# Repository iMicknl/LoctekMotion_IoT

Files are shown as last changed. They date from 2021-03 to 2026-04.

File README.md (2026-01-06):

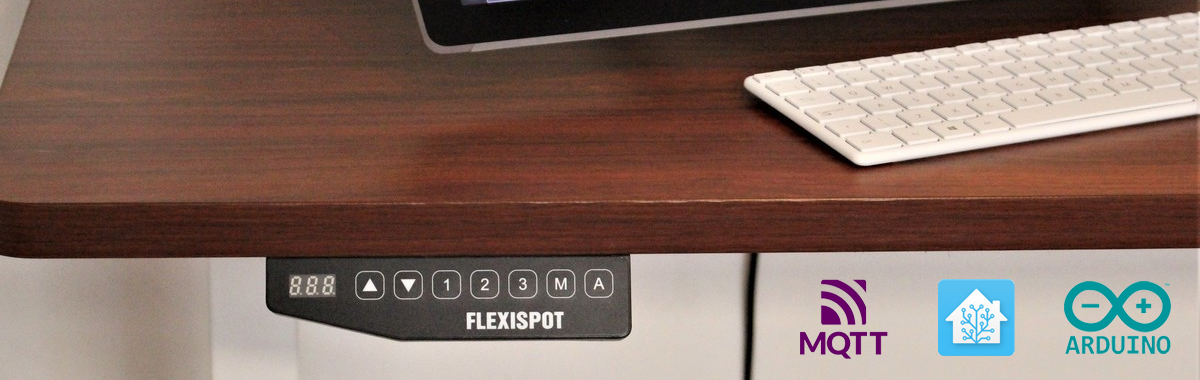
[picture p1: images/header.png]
Flexispot Desk with automation logos

(*image source: [Windows Central](https://www.windowscentral.com/flexispot-e5-standing-desk-review)*)

> [!WARNING]
> Be careful. Tinkering with electronics can be risky. Use this guide at your own risk.

## Turn your LoctekMotion/FlexiSpot desk into a smart desk

When I assembled my FlexiSpot standing desk, I noticed the control panel had an RJ45 cable and a second RJ45 port. This sparked my interest: can I connect my desk to the internet?

Most Flexispot models utilize components from LoctekMotion, a manufacturer specializing in lifting columns for height-adjustable desks. Although LoctekMotion previously advertised a [Bluetooth receiver](https://www.loctekmotion.com/shop/accessories/bt-desk-app/) for their control boxes, I haven't been able to obtain one.

This repository will guide you on connecting your desk to Home Assistant and other systems using the serial communication ports (RJ45). Imagine controlling your desk with your voice or receiving notifications when you've been sitting too long. Or, just do it because it's cool 🤓.

## Features

- Control your desk (up, down, stop) using a cover entity
- Manage 4 presets with button entities
- Monitor desk height with a sensor entity
- Adjust desk height in cm using a number entity *(experimental)*

#### Known issues

- Number entity may overshoot. The desk moves until the height sensor matches the requested height, which may cause overshooting due to reporting delays. Use the desk controller presets for accurate positioning.

## Packages

| Name | Description |
| --- | --- |
| [ESPHome](packages/office-desk-esp32.yaml) | Control your desk via an ESP32 module connected to Home Assistant. Can be adapted to ESP8266 or other ESP32 variant. |
| [ESPHome Pass-through](packages/office-desk-esp32-passthrough.yaml)  | Control desks which have only one RJ45 port using passthrough configuration via an ESP32 module connected to Home Assistant. |

For v1 packages (Arduino, Raspberry Pi, older ESPHome packages, and different pin-outs), visit the [`archive`](./archive/) directory. For alternative solutions, see [similar projects](#similar-projects).

## Getting started

Please follow the [ESPHome documentation](https://esphome.io/guides/getting_started_command_line.html) for the basics of ESPHome. You can use the provided [`office-desk-esp32.yaml`](https://github.com/iMicknl/LoctekMotion_IoT/blob/main/packages/office-desk-esp32.yaml) as a boilerplate for your own implementation. This implementation has been created for the ESP32 nodemcu, but can easily be adopted for other platforms and boards.

### Pin-out

| RJ45 pin | Name | ESP32 |
| --- | --- | --- |
| 8 | +5V (VDD) | VIN |
| 7 | GND | GND |
| 6 | TX | TX2 (GPIO17) |
| 5 | RX | RX2 (GPIO16) |
| 4 | PIN 20 | D23 (GPIO23) |
| 3 | (unknown) | |
| 2 | SWIM | |
| 1 | RES | |

This pin-out should be compatible with all control panels featuring an RJ45 port for serial communication. If it doesn't work for your setup, consider trying an alternative pin-out from the [archive](./archive/esphome/README.md).

Use the provided pin-out to connect your ESP32 to the desk controller's RJ45 port using an ethernet cable. If you're not experienced with electronics and soldering, consider using an RJ45 Adapter Board from sites like Aliexpress, connected with Dupont cables to your ESP32.

example setup

#### Pass-Through Configuations

If your desk controller lacks an extra RJ45 port, you'll need a pass-through solution. This requires connecting the RJ45 of the keypad to the pins below.

| KeyPad RJ45 pin | Name | Connection
| --- | --- | ---
| 8 | +5V (VDD) |  VIN  (Split)
| 7 | GND |  GND  (Split)
| 6 | TX |  RX0  (GPIO3)
| 5 | RX |  RX2  (Split)
| 4 | PIN 20 |  (Not Required)
| 3 | (unknown) |  (Not Required)
| 2 | SWIM |  (Pass-Through)
| 1 | RES |  (Pass-Through)

The pins marked 'split' are to be connected to the ESP32 pin, the desk controller and to the keypad. The pins marked pass-through are to be connected directly between the controller and the keypad.

Note: the current implementation does not utilize PIN20 however, this could be utilized to sense if the screen is on if desired.

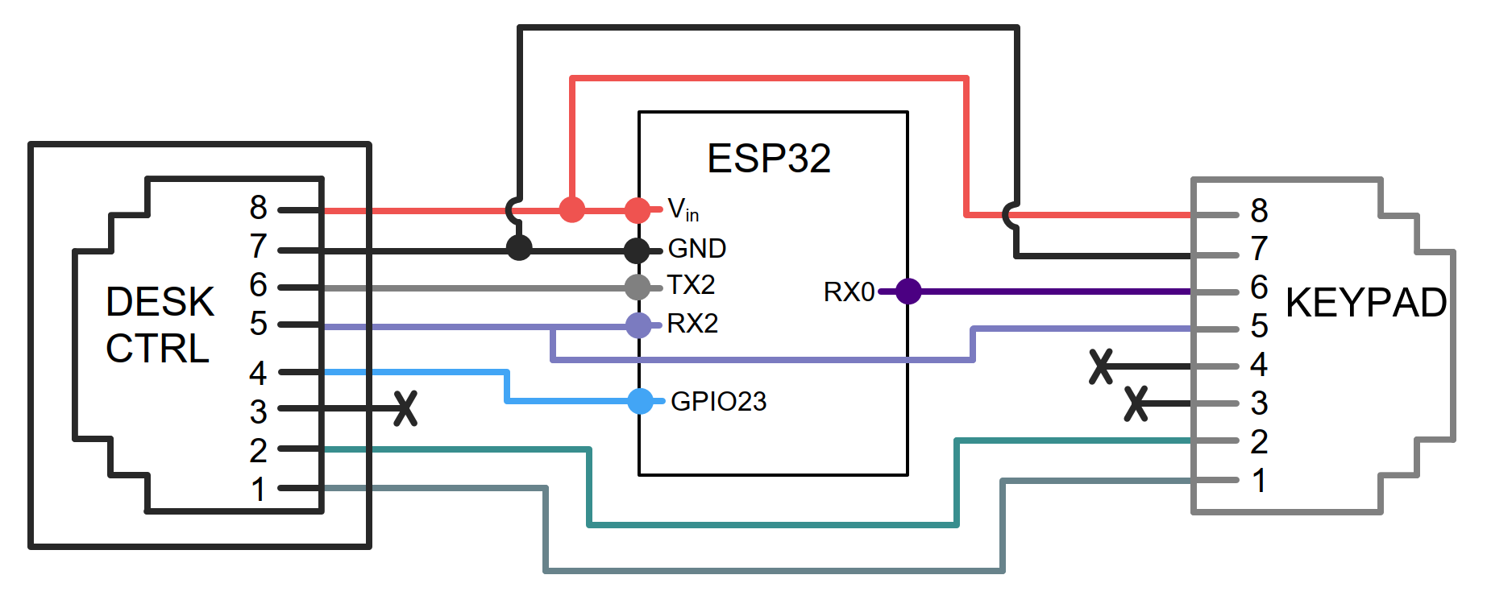
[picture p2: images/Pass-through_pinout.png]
Pass-Through Pinout


### Optional: Custom Enclosure for a Clean Setup

To keep your setup clean and well-protected, a custom enclosure for the ESP32 DevKit with Ethernet breakout is available. It ensures secure housing, optimal cable management, and a stable wired connection.

Features ✅:
- Secure housing – Protects the ESP32 and Ethernet breakout
- Optimized cable management – Keeps wiring neat and organized
- Ventilation slots – Prevents overheating
- Easy mounting – Designed for a hassle-free installation
- Compact design – Fits seamlessly into any setup

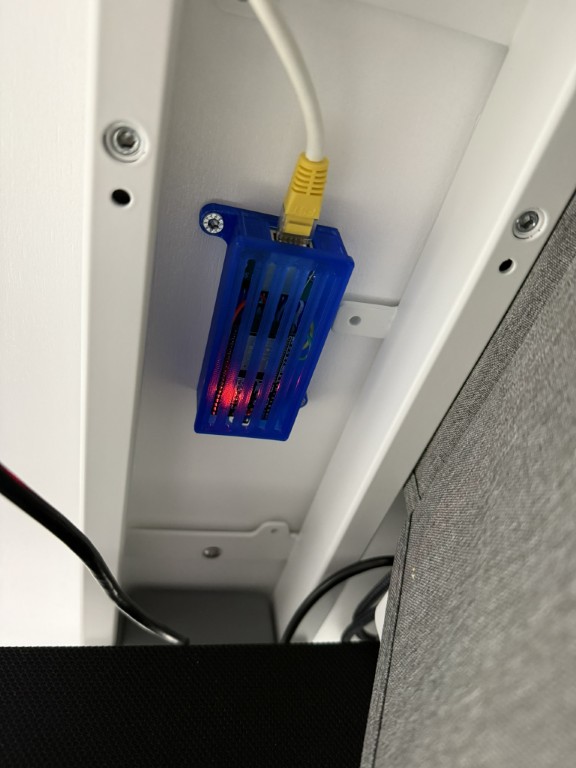
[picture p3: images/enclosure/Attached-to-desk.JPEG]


🔗 Download the enclosure model at [makerworld.com](https://makerworld.com/de/models/1220796-flexispot-smartdesk-enclosure-esp32-devkit-lan#profileId-1237633).

### Troubleshooting

**My height sensor is not providing the correct value**
- Uncomment the debug line for UART in the ESPHome configuration to see the raw data coming from the desk controller. This will help you collect information to troubleshoot the issue. See [debugging UART](https://esphome.io/components/uart.html#debugging).
- If your cover entity has up/down buttons grayed out due to height sensor issues, you can change the internal parameter for the up/down switch from `true` to `false`in the YAML configuration.

## Research

If you are interested in the internals of the LoctecMotion desk system, have a look at the research below which is composed of my own findings combined with findings of [similar projects](#similar-projects).

<details>

<summary>Full research</summary>

### Control Panels

At the time of writing, LoctekMotion sells [11 different control panels](https://www.loctekmotion.com/product/control-panel/). The features can differ per model, but it looks like the serial interface is pretty similar for the more advanced models.

The tables below will show a mapping of the RJ45 pinout to the pinout used by the control panel. Please note that all RJ45 pins are described in the following way:

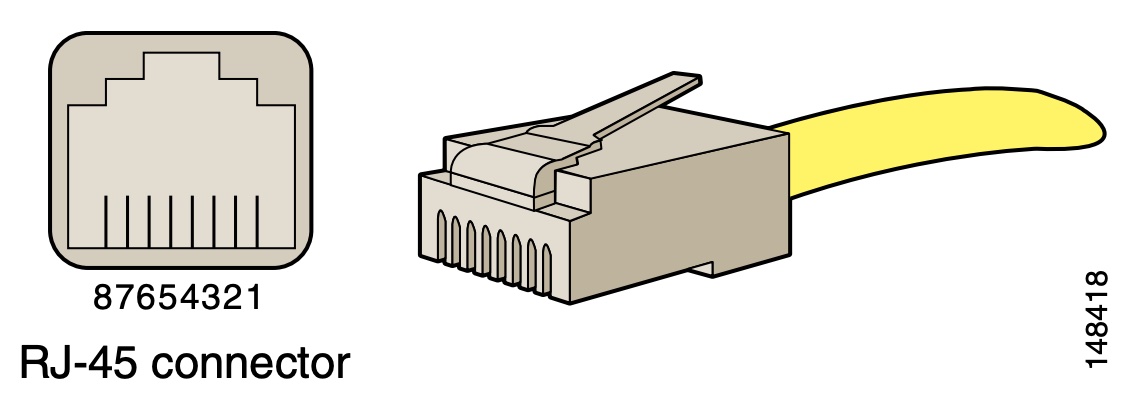
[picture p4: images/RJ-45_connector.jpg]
RJ-45 connector layout


The most common [color convention](https://www.showmecables.com/blog/post/rj45-pinout)
for wiring RJ45 for network cables is:

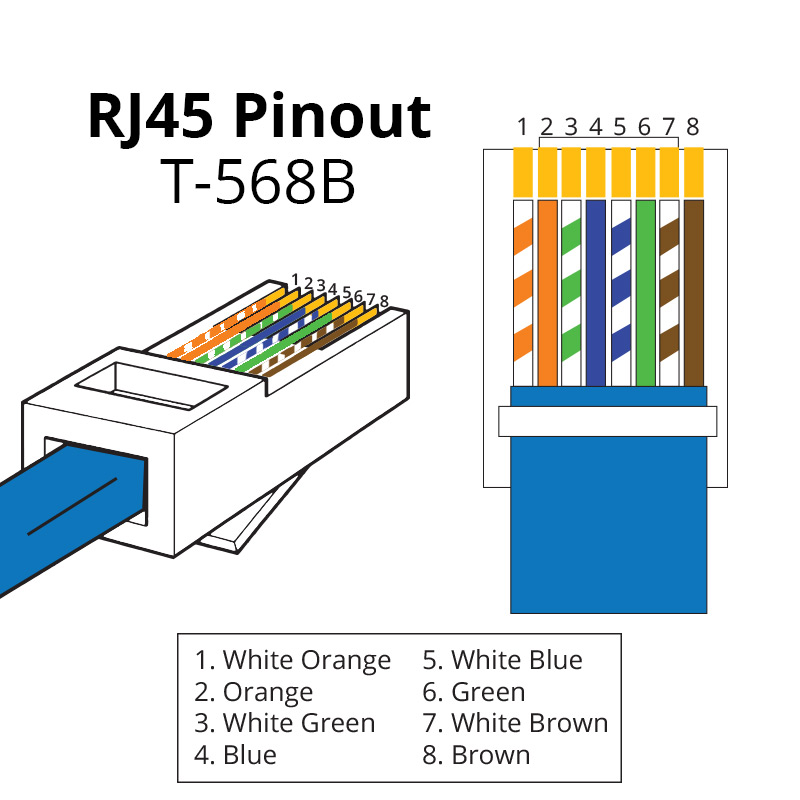
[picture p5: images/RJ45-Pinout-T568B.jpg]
RJ45 T568B colors


In order to connect the control box to a Raspberry Pi and ESP32/ESP8266 chip I used a [RJ45 to RS232 adapter](https://www.allekabels.nl/rs232-kabel/4568/1041186/rj45-naar-rs232.html) with DuPont cables (jump wires), but you simply can cut and split an ethernet cable as well.

#### Supported Control Panels
<!-- prettier-ignore-start -->
<!-- markdownlint-disable -->
<table>
  <tr>
    <td align="center"><a href="#hs13b-1"><br /><sub><b>HS13B-1</b></sub></a></td>
    <td align="center"><a href="#hs13a-1"><br /><sub><b>HS13A-1</b></sub></a></td>
    <td align="center"><a href="#hs01b-1"><br /><sub><b>HS01B-1</b></sub></a></td>
  </tr>
</table>
<!-- markdownlint-enable -->
<!-- prettier-ignore-end -->

> [!NOTE]
> Eventually, we discovered that a single pin-out should work for all control panels. It seems multiple mappings can be used, but the most common one is the one used for the HS13B-1 control panel.

#### HS13B-1

- **Desk model**: Flexispot E7
- **Tested with control box**: CB38M2J(IB)-1
- **Source**: Printed on the PCB of the control box.

| RJ45 pin | Name | Original Cable Color | Ethernet cable color (T568B) |
| --- | --- | --- | --- |
| 1 | RESET | Brown | White-Orange |
| 2 | SWIM | White | Orange |
| 3 | EMPTY | Purple | White-Green |
| 4 | PIN 20 | Red | Blue |
| 5 | RX | Green | White-Blue |
| 6 | TX | Black | Green |
| 7 | GND | Blue | White-Brown |
| 8 | +5V (VDD) | Yellow | Brown |

Note that RX and TX is defined like this on receiver (control panel) side.
So the custom controller also uses RX to receive data and TX to send data.

#### HS13A-1

- **Desk model**: Flexispot EK5
- **Tested with control box**: CB38M2B(IB)-1
- **Source**: Printed on the PCB of the control box.

| RJ45 pin | Name | Original Cable Color | Ethernet cable color (T568B) |
| --- | --- | --- | --- |
| 1 | RESET SWIM | Brown | White-Orange |
| 2 | PIN 20 | White | Orange |
| 3 | RX | Purple | White-Green |
| 4 | TX | Red | Blue |
| 5 | GND1 | Green | White-Blue |
| 6 | +5V (VDD)  | Black | Green |
| 7 | 29V+ | Blue | White-Brown |
| 8 | 29V- | Yellow | Brown |

Note that RX and TX is defined like this on receiver (control panel) side.
So the custom controller also uses RX to receive data and TX to send data.

#### HS01B-1

- **Desk model**: Flexispot E5B
- **Tested with control box**: CB38M2A-1
- **Source**: [nv1t/standing-desk-interceptor](https://github.com/nv1t/standing-desk-interceptor)

| RJ45 pin | Name |
| --- | --- |
| 8 | +5V (VDD) |
| 7 | GND |
| 6 | TX |
| 5 | RX |
| 4 | PIN 20 |
| 3 | (unknown) |
| 2 | SWIM |
| 1 | RES |

Note that RX and TX is defined like this on receiver (control panel) side.
So the custom controller also uses RX to receive data and TX to send data.

Other control panels / control boxes could be supported in the same way, but you would need to figure the RJ45 pinout mapping. Most control boxes have an extra RJ45 port for serial communication, but otherwise you would need to place your device in between the control panel and the control box.

### Retrieve current height

Based upon the great work of [minifloat](https://www.mikrocontroller.net/topic/493524), it became clear that the control panel utilises a [7-segment display](https://en.wikipedia.org/wiki/Seven-segment_display). Fortunately, this is very common in such devices and thus there is a lot of [documentation](https://lastminuteengineers.com/seven-segment-arduino-tutorial/) on this topic.

The control box sends the height as 4-bit hexadecimal, which is decoded in the control panel to drive the 7-segment display. The second number on the display also supports an optional decimal point ("8 segment").

Make sure you set the baud rate to 9600. For most LoctekMotion desks, the control box only broadcasts the current height for x seconds after you sent the Wake Up command. Otherwise you will receive `0x00` `0x00` `0x00` as payload.



source: [alselectro](https://alselectro.wordpress.com/2015/03/03/8051-tutorials-3-interfacing-7-segment-display/)

### Execute a command

The control box only accepts commands when the 'screen is active'. To activate the screen, `PIN 20` needs to be set to HIGH for about 1 second. The screen gets disabled automatically again after some amount of time receiving no commands.

#### Command list

| Command name | Start | Length | Type | Payload | Checksum  | End  |
| --- | ----- | --- | ---- | --- | --- | ---- |
| Wake Up | `9b`  | `06` | `02` | `00` `00` | `6c` `a1` | `9d` |
| Up | `9b`  | `06` | `02` | `01` `00` | `fc` `a0` | `9d` |
| Down | `9b`  | `06` | `02` | `02` `00` | `0c` `a0` | `9d` |
| M | `9b`  | `06` | `02` | `20` `00` | `ac` `b8` | `9d` |
| Preset 1 | `9b`  | `06` | `02` | `04` `00` | `ac` `a3` | `9d` |
| Preset 2 | `9b`  | `06` | `02` | `08` `00` | `ac` `a6` | `9d` |
| Preset 3 (stand) | `9b`  | `06` | `02` | `10` `00` | `ac` `ac` | `9d` |
| Preset 4 (sit) | `9b`  | `06` | `02` | `00` `01` | `ac` `60` | `9d` |

All bytes combined will become the command to send to the control box. See the [packages](#packages) for sample code.

</details>

### Similar projects

While working on this project, I found that many others have done similar work. Several GitHub repositories with great research have been very helpful in starting this project. ❤️

- [grssmnn / ha-flexispot-standing-desk](https://github.com/grssmnn/ha-flexispot-standing-desk) - Home Assistant integration via MQTT (micropython)
- [Dude88 / loctek_IOT_box](https://github.com/Dude88/loctek_IOT_box) - Arduino code to control via Alexa and MQTT
- [nv1t / standing-desk-interceptor](https://github.com/nv1t/standing-desk-interceptor) - Research on intercepting commands from Flexispot desks
- [VinzSpring / LoctekReverseengineering](https://github.com/VinzSpring/LoctekReverseengineering#assumptions) - Research and Python samples

Special thanks to the [Tweakers.net](https://gathering.tweakers.net) community (Dutch) for helping kickstart this project.

## Contributions

We welcome contributions from the community! If you have ideas, suggestions, or improvements, please feel free to open an issue or submit a pull request.

## Support

Join our [Discord channel](https://discord.gg/C7TNzUZ9Xf) for a chat with like-minded people or to get help with your project.

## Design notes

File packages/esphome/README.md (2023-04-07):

# ESPHome

>ESPHome is a system to control your ESP8266/ESP32 by simple yet powerful configuration files and control them remotely through Home Automation systems.

## HS13B-1

| ESP8266 | Loctek Motion (HS13B-1) | Loctek Motion Cable Color (HS13B-1)|Ethernet cable color (T568B)|
| --- | --- | --- |---|
| GND | GND | Blue | White-Brown |
| D6 | RX | Green | White-Blue |
| D5 | TX | Black | Green |
| D2 | PIN 20 | Red | Blue |

## HS13A-1

| ESP8266 | Loctek Motion (HS13A-1) | Loctek Motion Cable Color (HS13A-1)|Ethernet cable color (T568B)|
| --- | --- | --- |---|
| GND | GND | Green | White-Blue |
| D6 | RX | Purple | White-Green|
| D5 | TX | Red | Blue |
| D2 | PIN 20 | White | Orange|

## HS01B-1

| ESP8266 | Loctek Motion (HS01B-1) | Loctek Motion Cable Color (HS01B-1)| Ethernet cable color (T568B)|
| --- | --- | --- |---|
| GND | GND | Blue | White-Brown |
| D6 | RX | Green | White-Blue |
| D5 | TX | Black | Green |
| D2 | PIN 20 | Red | Blue |

## [HS01B-1] with ESP32 as passthrough and keypad support

| ESP32 | Loctek Controller (E5) | Loctek Motion Cable Color (HS01B-1)|
| --- | --- | --- |
| GND | GND | Blue |
| GPIO16  | RX | Green |
| GPIO17  | TX | Black |
| GPIO23  | PIN 20 | Red |

| ESP32 | Loctek keypad (HS01B-1) |Loctek Motion Cable Color (HS01B-1) |
| --- | --- | --- |
| | GND | Blue  (Bridged to GND from controller)|
| | RX | Green (Bridged to RX from controller) |
| GPIO3 | TX | Black |
| GPIO22  | PIN 20 | Red |

Note: The rest of the cables can be passed through directly to the controller from the keypad. RX from controller is split between the Keypad and ESP directly

See [README](../../README.md#control-panels) for more details. If your board supports a 5V input, you could use the 5V provided by the control box to power your controller as well:

| ESP8266 | Loctek Motion (HS13A-1) | Loctek Motion (HS01B-1) |
| --- | --- | --- |
| GND | GND | GND |
| D6 | RX | RX |
| D5 | TX | TX |
| D2 | PIN 20 | PIN 20 |
| VIN | +5V (VDD) | +5V (VDD) |

## Installation

Please refer to the [ESPHome documentation](https://esphome.io/guides/getting_started_command_line.html).

You can use `flexispot_ek5.yaml` *(HS13A-1, HS13B-1)* or `flexispot_e5b.yaml` *(HS01B-1)* as a boilerplate for your own implementation. This implementation has been created for the ESP8266 nodemcu, but can easily be adopted for other platforms and boards.

## Features

- Up to 4 presets as switch entities
- Up / Down controls via cover entity
- Current height via sensor entity
- M button via switch entity
- Wake up button via switch entity (currently just used for testing, doesn't seem functional yet)
- Support for ESP32 (E5b only)
- Support for keypad (E5b only)

## Screenshots
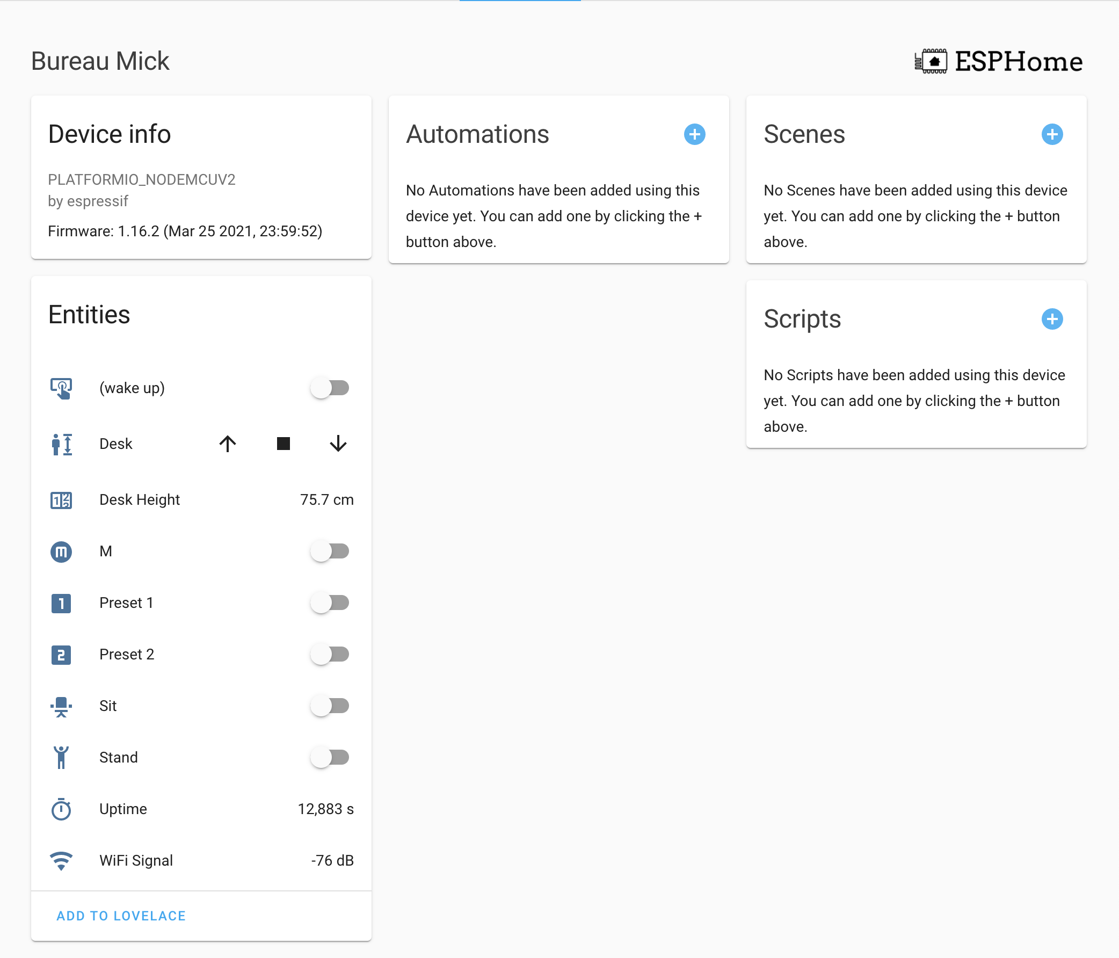
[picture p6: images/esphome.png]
ESPHome in Home Assistant


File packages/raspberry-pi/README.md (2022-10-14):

# Raspberry Pi

The Raspberry Pi is a low cost device which is found in many households. A powerful feature of the Raspberry Pi is the row of GPIO (general-purpose input/output) pins along the top edge of the board. These GPIO pins can be used to interact with the LoctekMotion control box.

In the end I believe the Raspberry Pi is overkill for this scenario, but if you have a spare one or if you want to experiment, give it a try. The Python script in this part is limited, but can easily be extended to fix your scenario.

## Prerequisites

- Raspberry Pi (with GPIO headers)
- Material to connect to the RJ45 port

## Installation

GPIO Pinout Diagram


Connect the GND, TX, RX and PIN20 (see [README](../../README.md#control-panels)) to the Raspberry Pi. In the Python script we use the following pins, but you can adapt this to your wishes.

| Raspberry Pi | Loctek Motion |
| --- | --- |
| 6 | GND |
| 8 (GPIO 14)  | RX |
| 10 (GPIO 15) | TX |
| 12 (GPIO 18) | PIN 20 |

## Install

Run `raspi-config` to turn on the serial connection. Go to Advanced Options -> Serial and enable the serial connection. You don't need to enable it for login.

`sudo apt-get install python3-rpi.gpio`

Browse to the folder where you placed the `flexispot.py` file.

`python3 -m venv venv`

`source venv/bin/activate`

`python3 flexispot.py up`

## Usage
Example usage: `python3 flexispot.py [COMMAND]`
- `python3 flexispot.py up`
- `python3 flexispot.py down`
- `python3 flexispot.py preset_1`

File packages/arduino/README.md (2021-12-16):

# Arduino

| ESP8266 | Loctek Motion |
| --- | --- |
| GND | GND |
| D5 (GPIO12) | RX |
| D6 (GPIO14) | TX |
| D2 (GPIO4)  | PIN 20 |

#### flexispot_ek5.ino

- outdated

#### flexispot_e8.ino

- tested with HS13A-1 + CB38M2L(IB)-1
- only works if HS13A-1 is wired like HS01B-1
- based on flexispot_ek5.ino
- 'unsigned long' replaced with 'const byte' to prevent compiler errors
- implements
  - demo()
  - turnon()
  - wake()
  - sit()
  - stand()
- flushes, enables and disables tx

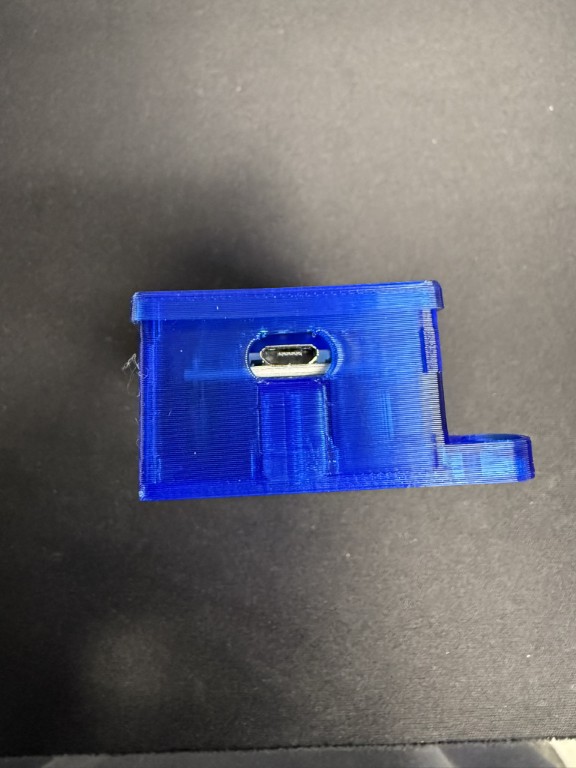
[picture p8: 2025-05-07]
images/enclosure/ESP32-Microsub-port.JPEG

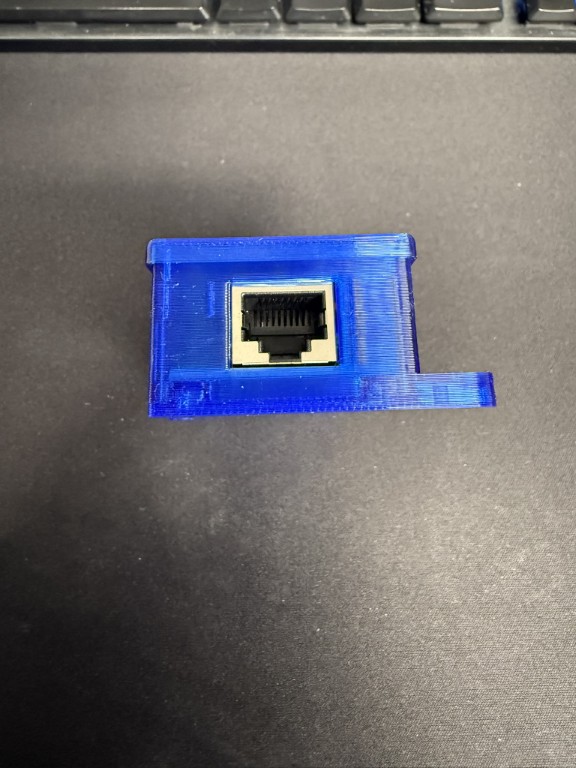
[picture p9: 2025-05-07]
images/enclosure/RJ45-Port.JPEG

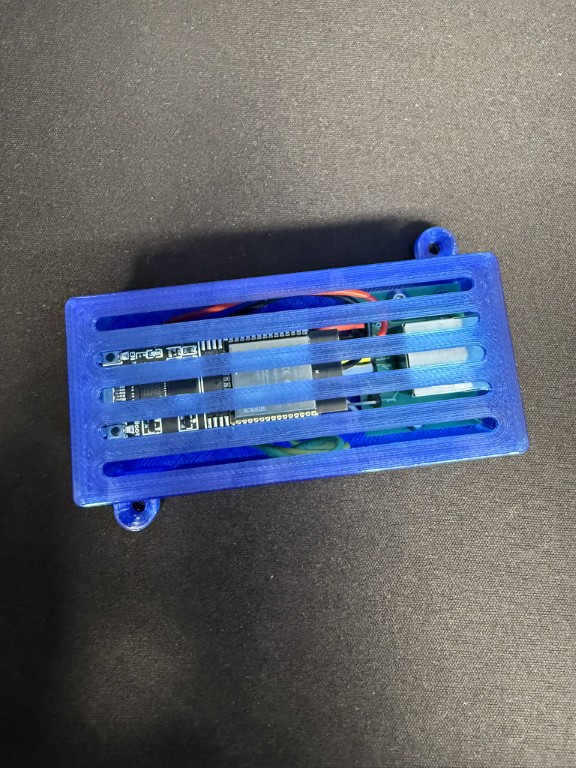
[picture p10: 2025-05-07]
images/enclosure/Closed.JPEG

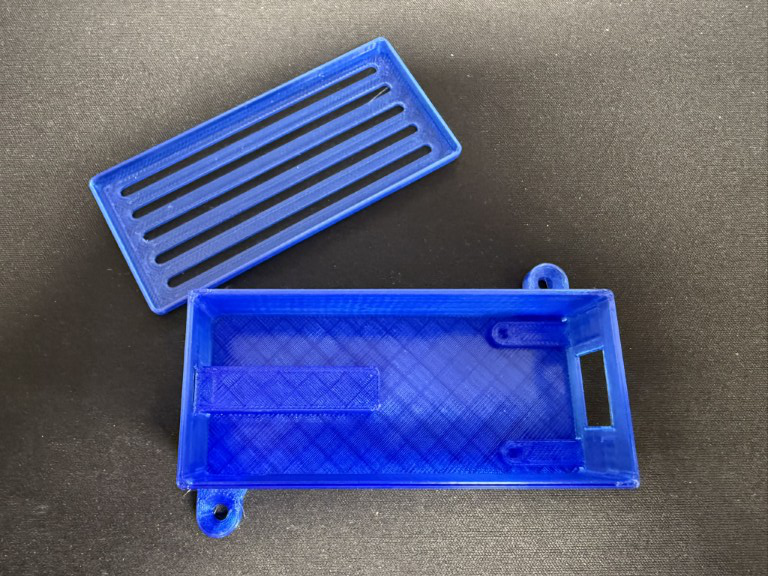
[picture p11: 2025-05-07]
images/enclosure/Base-Lid.JPEG

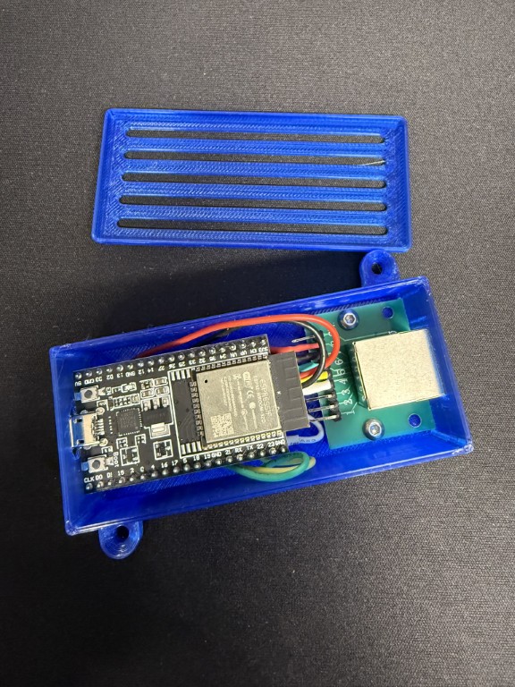
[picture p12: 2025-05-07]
images/enclosure/With-ESP-RJ45-Boards.JPEG

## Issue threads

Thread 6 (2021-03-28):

[HS01B-1] None of the commands work

staxDB, 2021-03-28:
Hey, damn cool project and just what I was looking for!

I am having a few issues in my setup though: I have been trying ,to control a flexispot desk remotely. Unfortunately none of the scenarios work.
I first tried the ESPHome solution and used an ESP8266. Since this did not work (or my desk did not respond at all), I still tried the variant with the Raspberry Pi - Unfortunately also unsuccessful. I even tried to execute the single "Up" command alone with a Python script, but the desk does not react to it.

Which setup I have: A Flexispot E5B with an HS01B-1 control unit and a CB38M2A-1 control module. I connected the Raspberry Pi and also the ESP8266 to the control module (CB38M2A-1) via a modified Ethernet cable. For the correct ethernet cable mapping I used this table as a guideline:
https://github.com/deskmatik/deskmatik#wiring-flexispot

Do you have any idea where I made a mistake? Is my control module possibly not compatible, since I also have only one Ethernet port?

iMicknl, 2021-03-28:
Have you tried reversing the TX / RX cables? This is very messy always and I had those reversed many many times during the development. The PIN20 is a very important one as well, since this allows you to send commands.

Could you perhaps share more here about how you configured the cables and how you set up the ESPHome yaml?

The Raspberry Pi code could use some love by the way, I just used this during the testing. The ESPHome code should work and this is what I am currently using.

Happy to walk through it on Discord as well, iMick#1903.

lordfiSh, 2021-03-31:
Same Problem here, also tried to switch RX/TX

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

```
substitutions:
  device_name: Flexispot EK5
  name: flexispot_ek5
  min_height: "73.6" # Min height + 0.1
  max_height: "122.9" # Max height - 0.1

esphome:
  name: ${name}
  comment: ${device_name}
  platform: ESP8266 # TODO Change to your platform
  board: nodemcuv2 # TODO Change to your board
  includes:
    - desk_height_sensor.h

wifi:
  ssid: !secret esphome_wlanssid
  password: !secret esphome_wlanpw

  # Enable fallback hotspot (captive portal) in case wifi connection fails
  ap:
    ssid: "${device_name} Fallback Hotspot"
    password: !secret esphome_web_pass

captive_portal:

# Enable logging
logger:
  #level: DEBUG
  baud_rate: 0

# Enable Home Assistant API
api:
  password: !secret esphome_ota

ota:
  password: !secret esphome_ota

uart:
  id: desk_uart
  baud_rate: 9600
  tx_pin: D7
  rx_pin: D8

sensor:
  - platform: wifi_signal
    name: "WiFi Signal"
    update_interval: 60s

  - platform: uptime
    name: Uptime

  - platform: custom
    lambda: |-
      auto desk_height_sensor = new DeskHeightSensor(id(desk_uart));
      App.register_component(desk_height_sensor);
      return {desk_height_sensor};
    sensors:
      id: "desk_height"
      name: Desk Height
      unit_of_measurement: cm
      accuracy_decimals: 1
      icon: "mdi:counter"

switch:
  - platform: gpio
    name: "Virtual Screen"
    pin:
      number: D5
      mode: OUTPUT
    restore_mode: ALWAYS_OFF
    internal: true

  - platform: uart
    name: "Preset 1"
    id: switch_preset1
    icon: mdi:numeric-1-box
    data: [0x9b, 0x06, 0x02, 0x04, 0x00, 0xac, 0xa3, 0x9d]
    uart_id: desk_uart

  - platform: uart
    name: "Preset 2"
    id: switch_preset2
    icon: mdi:numeric-2-box
    data: [0x9b, 0x06, 0x02, 0x08, 0x00, 0xac, 0xa6, 0x9d]
    uart_id: desk_uart

  - platform: uart
    name: "Sit" # Preset 3 on some control panels
    id: switch_sit
    icon: mdi:chair-rolling
    data: [0x9b, 0x06, 0x02, 0x00, 0x01, 0xac, 0x60, 0x9d]
    uart_id: desk_uart

  - platform: uart
    name: "Stand" # Not available for all control panels
    id: switch_stand
    icon: mdi:human-handsup
    data: [0x9b, 0x06, 0x02, 0x10, 0x00, 0xac, 0xac, 0x9d]
    uart_id: desk_uart

  - platform: uart
    name: "Up"
    id: switch_up
    icon: mdi:arrow-up-bold
    data: [0x9b, 0x06, 0x02, 0x01, 0x00, 0xfc, 0xa0, 0x9d]
    uart_id: desk_uart
    internal: true

  - platform: uart
    name: "Down"
    id: switch_down
    icon: mdi:arrow-down-bold
    data: [0x9b, 0x06, 0x02, 0x02, 0x00, 0x0c, 0xa0, 0x9d]
    uart_id: desk_uart
    internal: true

  - platform: uart
    name: "M"
    id: switch_m
    icon: mdi:alpha-m-circle
    data: [0x9b, 0x06, 0x02, 0x20, 0x00, 0xac, 0xb8, 0x9d]
    uart_id: desk_uart

  - platform: uart
    name: "(wake up)" # Not available on all control panels
    id: switch_wake_up
    icon: mdi:gesture-tap-button
    data: [0x9b, 0x06, 0x02, 0x00, 0x00, 0x6c, 0xa1, 0x9d]
    uart_id: desk_uart

cover:
  - platform: template
    # icon: mdi:table-chair
    # icon: mdi-human-male-height-variant
    name: "Desk"
    assumed_state: true

    # Move desk up
    open_action:
      - while:
          condition:
            sensor.in_range:
              id: desk_height
              below: ${max_height}
          then:
          - logger.log: "Executing up command"
          - switch.turn_on: switch_up
          - delay: 10ms

    # Move desk down
    close_action:
      - while:
          condition:
            sensor.in_range:
              id: desk_height
              above: ${min_height}
          then:
          - logger.log: "Executing down command"
          - switch.turn_on: switch_down
          - delay: 10ms
    optimistic: true
```

iMicknl, 2021-03-31:
@staxDB I just discussed this issue briefly with @lordfiSh and he is indeed facing similar issues. Looking at DeskMatic, it seems that they set the PIN20 to HIGH, where I use LOW.

Perhaps the following works;

```
  - platform: gpio
    name: "Virtual Screen"
    pin:
      number: D2
      mode: OUTPUT
    restore_mode: ALWAYS_OFF
    internal: true
```

Set restore_mode to `ALWAYS_ON`, or remove the `internal` and toggle it yourself during testing.

staxDB, 2021-04-04:
I just tried the customization: It seems to work! However, I have also changed the PIN assignment:
PIN20 = D5
RX = D7
TX = D8

iMicknl, 2021-04-04:
@staxDB are you able to do a pull request on this repo to add better instructions for HS01B-1? I will investigate the `ALWAYS_ON`/ `ALWAYS_OFF` differences between our model and document that in a better way.

iMicknl, 2021-04-05:
Should be fixed with [new ESPHome sample](https://github.com/iMicknl/LoctekMotion_IoT/tree/main/packages/esphome), thanks @staxDB.

Closed 2021-04-04.

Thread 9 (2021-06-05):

Wakeup Issues with Esphome

Algram, 2021-06-05:
Hi there,

I've successfully integrated my flexispot desk to Home Assistant using your project. Thanks for that!

One problem I am having is, that I need to trigger the wakeup switch (and wait like 5 seconds) before I can send presets events.
Is there any way that this could be more integrated? Ideally I would like to just trigger the preset and the desk to always react.

Thanks!

iMicknl, 2021-06-06:
Great to hear! Which desk do you own?

Perhaps you could execute the wake up switch on `switch.turn_on`, however I am not sure if this will be the right order. https://esphome.io/components/switch/index.html#switch-turn-on-action

Algram, 2021-06-07:
@iMicknl  I am using the Flexispot E07 with the HS01B-1 control panel.

I thought about sending the wakeup event before the actual event, but there seems to be a big delay between the wakeup event and the other switches working. I also have to press the wakeup button multiple tims which seems weird.

N1c093, 2021-06-08:
@Algram Do you shut down your complete desk and ESP everyday?

I do so and implement this workaround for me, which seems to work fine. I send the button "M" to my table after the ESP is booted. After this the ESP can control the table all over the time.

I'm using "Flexispot EK2" with "HS13A-1" Control Panel and "CB38M2B(IB)-1" Control Box

```yaml

esphome:
  name: ${name}
  comment: ${device_name}
  platform: ESP8266 # TODO Change to your platform
  board: nodemcuv2 # TODO Change to your board
  includes:
    - desk_height_sensor.h
  on_boot:
    priority: -10
    then:
      - switch.turn_on: switch_m

```

Maybe this will also resolve your issue?

XPStef, 2022-02-22:
Hi there,

I own a Flexispot E7 as well and have deployed ESPHome on a D1 Mini Pro. Haven't disassembled the control panel but checked the wire output of the second RJ45 port and it matches the HS01B-1 pin layout (it has a touchscreen, though). At the moment using the built in web server for testing purposes.

What I've noticed is that the wake up toggle doesn't work for me at all (even after pressing it multiple times, trying to send e.g. the UP command afterwards, no luck...). Either the control panel has to be woken up first (displaying the current height) or the PIN20 (of the internal Virtual Screen) has to be set to HIGH/ON (restore_mode is ALWAYS_OFF on boot) to be able to send a command to the desk. Afterwards it works like expected.

Nevertheless, after waking up the display of the control panel or setting PIN20 to HIGH and sending a command to the desk, the control panel executes button presses differently. By default, when pressing a button, the display turns on first (displaying the current height) and after a delay of 1-2 seconds executes the command of the pressed button. After controlling the desk via the D1 Mini, the button presses on the control panel get executed immediately. This behavior stays like that until the desk gets rebooted/reconnected even after disconnecting the D1 Mini beforehand.

There is something different when using the control panel by itself, getting/displaying the current height of the table and then executing the button press and using ESPHome because it changes the behavior of the control panel or changes something in the control box that button presses get executed immediately.

Does anybody have a solution to circumvent this behavior?

@Algram: Have you found a solution for your problem? Maybe I (and others) can benefit from it as well :)

Thank you @iMicknl for the great project 👍

Algram, 2022-02-22:
@XPStef I still have the same issue and also have not found a way to fix it yet. So I am really interested in what you'll find too!

iMicknl, 2022-02-22:
> When waking up the display (displaying the current height), PIN20 receives a voltage of ~2.8V. When the display turns of, no voltage is applied anymore. Testing this by sending the wake up command, the voltage stays at 0V. So I guess the control box of the E7 isn't compatible with the wake up command?

I don't think the wake up command works for anyone, I took this from another project, but couldn't get it working! Personally what I do is call the "M" button on wake up, so I always get the current height. And than after every command (on control panel or ESP) it will get the new height as well.

By the way, feel free to do a PR to add your findings / hints to our README. As you can see, we can use some better documentation. :)

Algram, 2022-02-22:
@iMicknl Even if I toggle the M button, UP/Down and Preset commands after that do not work. I have to press them around 10 times for them to get registered. I have no idea where this is coming from, but I think @XPStef is having similar problems.

XPStef, 2022-02-22:
> So I am really interested in what you'll find too!
>
> If you need me to test anything, just let me know, I'm down.

Not much unfortunately. But thanks for offering your help ;)

> I don't think the wake up command works for anyone, I took this from another project, but couldn't get it working! Personally what I do is call the "M" button on wake up, so I always get the current height. And than after every command (on control panel or ESP) it will get the new height as well.
>
> By the way, feel free to do a PR to add your findings / hints to our README. As you can see, we can use some better documentation. :)

I've tried the 'M' switch 'workaround'. Works indeed but PIN20 has still to be set to HIGH/ON. If it's set to LOW/OFF, executing the 'switch.turn_on: switch_m' command on boot doesn't work, unfortunately.

@Algram: Try to set the 'restore_mode' of the 'Virtual Screen' to 'ALWAYS_ON' to get rid of the multiple wake ups. The current height can then be obtained by switching on the 'M' switch on boot as @N1c093 and @iMicknl has mentioned. I could just verify it on my desk.

Furthermore, I think I got the H13A-01 instead of the HS01B-1 as mentioned in Issue #23. They got an E7 and E8 as well with the touchscreen interface.

> UPDATE: When waking up the display (displaying the current height), PIN20 receives a voltage of ~2.8V. When the display turns of, no voltage is applied anymore. Testing this by sending the wake up command, the voltage stays at 0V. So I guess the control box of the E7 isn't compatible with the wake up command?

I also noticed, that once PIN20 was set to HIGH from the D1 Mini, the control box starts to permanently deliver a voltage of ~2.8V on PIN20 even after the display turns off (it should then be 0V again) until the desk gets rebooted/reconnected. Weird stuff tbh.
I think there is another command which gets sent from the H13A-01 to the control box (getting the current height) before the respective command gets executed. By simply touching one of the buttons the display turns on (wakes up), on the second touch the respective command (of any pressed/touched button) gets executed. There has to be another command to 'wake up' the control panel/box and obtain the current height of the desk (in my opinion). Like: IF display is OFF: WAKEUP; ELSE EXECUTE command ...

Actually I wouldn't bother at all. Everything works (for me) like it should. But with the touchscreen control panel there is no protection against accidental touches anymore because the first touch to turn on the display or the delay of 1-2 seconds before executing the button press/touch is gone once the famous PIN20 got set to HIGH.

We'll see. Maybe someone is more practical in finding the right command/PIN/whatever :)

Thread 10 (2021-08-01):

[bug] HS13A-1 stuck on "LOC"

tsheaff, 2021-08-01:
Not sure this is a bug with this library, but I was playing around with connecting my arduino to the standing desk, and now I've noticed when plugging back in my original `HS13A-1` keypad, it's stuck in the `LOC` state. Not 100% sure how to reproduce, but it will not get out of this setting regardless of how I press the buttons. I've tried:

- hold down M for a long time
- hold down up and down for a long time
- powering on and off the control
- powering on and off the control box itself

After all of these it still just says `LOC` and will not move the desk up and down. I'm not sure how to debug whether it's an issue with the keypad itself, or with the box it connects to. Is any state stored in this box? My box model is `CB38M2B(IB)-1`

Has anyone else run into this issue? Any ideas how to resolve? Perhaps there's a calibration issue it's experiencing where it thinks the desk is on uneven surface or otherwise has faulty state, and has shut down motor controls into the `LOC` state? cc @iMicknl @staxDB 🙏

iMicknl, 2021-08-02:
Which code did you use?

I would start with the following steps first:

1. Disconnect your Arduino from the motor control box
2. Remove the power cable of your desk
3. Wait 60 seconds
4. Plug in the power cable of your desk
5. Did this solve your problem?

I have exactly the same control box and control panel, however I am using it with ESPHome + Home Assistant at the moment.

By the way, there are some new users figuring out how it works, thus they created a Discord server. Feel free to [join us on Discord](https://discord.gg/C7TNzUZ9Xf).

mad2xlc, 2021-12-18:
LOC means lock and can be triggered with a 5 seconds press on memory and also released the same way.
It's not a bug it's a feature :)
I haven't attached my desk to an esp but came across this issue and was worried about this bug. But i think everything is fine here.

@tsheaff
Were you able to solve the problem already?

iMicknl, 2022-01-05:
Thanks for the context @mad2xlc! Perhaps we should add this to the FAQ as well.

I will close this issue for now.

tsheaff, 2022-03-11:
Hey @iMicknl @mad2xlc apologies for the incredibly slow reply 😆

I have not managed to fix this issue with the above. Holding down the memory for 5 seconds definitely doesn't fix it, or I would've fixed this months ago. I'm thinking of just buying an new controller. Any thoughts on the best place to purchase one?

RinkMax, 2022-07-14:
Hi @tsheaff,
I am facing the same problem. Have you been able to solve the problem by now?

DJHansford, 2022-09-08:
In case anyone else stumbles on this, I had the same problem with my Sanodesk controller (HS13A-1), though I've never connected it to an Arduino board. It got stuck on child lock mode and pressing and holding M for 5 seconds didn't work.

I fixed it by pressing and holding the M button while removing the power socket. It beeped at me through this procedure until the residual power in the system died. Just before shutting off it flashed '5-'. Once powered back on it was unlocked. Could just be dumb luck but maybe it'll help someone else.

DJHansford, 2024-08-09:
I've just a variation of this bug, googled for the fix I found before and found my own comment (thanks previous me!). However, this time it was different, my keypad was stuck in locked mode but when I pressed the `M` button it only beeped once, not continuously. The fix above wouldn't work as a result. Instead, after playing around for a long time, I pressed the `1` and `2` buttons together for a few seconds and it beeped continuously at me, then pressing the `M` caused the same beeping and my fix above worked.

fundix, 2024-12-12:
I fixed it by holding M and power off ... still holding M and power on the table ... on display was 888, then I press and hold arrow down and M and table start working

Closed 2022-01-05.

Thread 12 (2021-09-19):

Miswired, still works

sharkzor, 2021-09-19:
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
Not really an issue, but i accidentally wired my CB38M2B(IB)-1 / HS13A-1

with the other wiring scheme.
Still worked! How can this be? According to the scheme it should have zapped the board with 23v and rx/tx doesnt line up.
Does the control box switch or has some handshake protocol ?
![Uploading 71A73EAE-CECF-4294-938D-9EB0BCF22594.jpeg…]()

iMicknl, 2021-09-19:
This is interesting! We had a discussion on the Discord a while ago about this, and we were wondering how multiple control panels could have different wirings. Perhaps the control box is able to recognize and switch the signal.

iMicknl, 2021-12-16:
@sharkzor could you perhaps share your wiring? It is hard to define that from the cable color.

Perhaps you can use the numbers from this image:
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

mad2xlc, 2021-12-18:
I have the same controller and control panel CB38M2L(IB)-1 and HS13A-1.
I measure 5V between pin 8 and 7, and between 8 and 4 (what is Pin20 i think).
So it makes no sense for me to use the pinout from https://github.com/iMicknl/LoctekMotion_IoT/blob/main/README.md#hs13a-1

MEfinger, 2021-12-28:
Hey @iMicknl,
I have done the same mistake as @sharkzor and wired my desk (CB38M2L(IB)-1 and HS13B-1) with the [HS01B-1 scheme](https://github.com/iMicknl/LoctekMotion_IoT#hs01b-1). So in my case the following pins are connected:

RJ45 pin | Name | Ethernet cable color (T568B) | Wemos D1
-- | -- | -- | --
8 | +5V (VDD) | Brown | 5V
7 | GND | White-Brown | GND
6 | TX | Green | D5
5 | RX | White-Blue | D6
4 | PIN 20 | Blue | D2

Everthing works as expected. The Wemos D1 gets its 5V from the Brown & White-Brown cable. The Desk gets the commands, so i assume the Rx and TX is correct too. The only problem is that the Desk Height Sensor sometimes changes its state to "Unknown" and the desk doesn't accept commands. So I assume the Pin 20 wiring is wrong, right?

sharkzor, 2021-12-29:
> @sharkzor could you perhaps share your wiring? It is hard to define that from the cable color.
>
> Perhaps you can use the numbers from this image: 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

Its the default wiring scheme B

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

mad2xlc, 2021-12-29:
In my setup the 5v drops to 4.8v and the wemos is getting unstable. I think you have similar problems. i will try it with an barebone esp8266 and a 3.3v ldo voltage regulator. Otherwise i will need an external power supply.

MEfinger, 2021-12-30:
Out of curiosity I tested the other wiring scheme (HS13A-1) and it did not work. The Wemos wouldn't turn on and the physical Keypad was stuck (The display turned on but I couldn't press any keys). I also tested the other RJ-45 Port to see if that would change something and even disconnected the physical keypad. But the result stayed the same. The moment I plug in a Wemos D1 with the HS13A-1 wiring scheme the Desk gets stuck and wont respond to the physical or the digital keypad. Even powering off the whole desk and then reconnecting the Wemos to the Port wouldn't help.
Do you guys have any idea on why only the other scheme works?

MEfinger, 2021-12-30:
Hey @iMicknl,
I think I found the issue with the wrong wiring scheme.
In the Readme the Pin Layout for the HS13A-1 is wrong.
I opened up my Control Box and compared the values on the PCB and saw that there are actually 10 cables connected to it.
So the Table in the Readme File should be changed (also the ethernet cable colors in the HS13A-1 table are swaped)

RJ45 pin | Name | Original Cable Color | Ethernet cable color (T568B)
-- | -- | -- | --
8 | RESET | Brown | White-Orange
7 | SWIM  | White | Orange
6 | empty | Purple | White-Green
5 | pin20| Red | Blue
4 | RX | Green | White-Blue
3 | TX | Black | Green
2 | GND1 | Blue | White-Brown
1 | +5V (VDD) | Yellow | Brown

The two cable underneath the 5V are separated from the RJ45 cable and belong to the powerplug. they deliver the 29V which I assume are used to power the USB port. Thats why only the HS13B-1 has them.

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

iMicknl, 2022-01-24:
@MEfinger I think you are correct! Would you be willing to do a PR to fix this? Or should I do this :).

Which YAML are you using? Do you set PIN20 to low or high?

Kienz, 2022-02-23:
Does anybody got CB38M2L(IB)-1  with HS13U and ESP8266 working? @MEfinger @mad2xlc

dasmith83, 2022-09-07:
I too have a CB38M2B(IB)-1 but my buttons are on a HS11A-1.

I tested the pins on both combinations (i.e. for the HS01B-1 and for the HS13A-1), I also found that for my HS11A-1 the correct configuration was the same as the HS01B-1.

I've used a NodeMCU ESP8266 with the config below:
RJ45 pin 8 as +5V going to Pin "VIN"
RJ45 pin 7 as GND going to Pin "GND"
RJ45 pin 6 as TX going to Pin "D5"
RJ45 pin 5 as RX going to Pin "D6"
RJ45 pin 4 going to Pin "D2"

Thanks to all those who've made this possible...works a treat!

irqnet, 2022-09-15:
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

I do have HS11A-1 connected to a  CB38M2**D**(**P**B)-1

Configuration seems not to work for me. As there is no dedicated RJ45 Port, I've just wired the Wemos D1 mini to the connector. I've just unsoldered D5 for tests, as the pysical buttons are not responding when everything is connected.

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

sickill, 2023-01-21:
I have **CB38M2L(IB)-9** with **HS13B-1** panel. The correct wiring for this combination is the same as for **HS01B-1**:

ESP32 pin    | RJ45 pin    | RJ45 cable color        
-------------|-------------|-------------
+5V          | 8           | brown
GND          | 7           | white-brown
17 (TX)      | 6           | green
16 (RX)      | 5           | white-blue
23 ("Pin20") | 4           | blue

Initially I used NodeMCU v3 (ESP8266) for this but I was experiencing some issues:

- it was unstable, resetting frequently - maybe related to the voltage drop to 4.8 @mad2xlc brought up (I measured and I'm seeing similar value)
- height readings had occasional glitches, showing 600.0 cm out of the blue

ESP8266 doesn't have hardware UART so it does it in software and it's not very robust (esphome docs on UART warn about that).

So now I'm using ESP32 DevkitC-32E for this, powering it from pin 8 +5V without any problems. It works flawlessly - always accurate height readings and super stable, never resets. ESP32 DevkitC-32E has LDO voltage regulator which to my knowledge converts it to 3.3V. Maybe that explains why it's stable with 4.8V or even 4.75 I measured on few occasions.

naresh97, 2023-02-03:
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

Can confirm, works on my HS13B-1.

260885El, 2024-03-19:
Good afternoon, query, is there another controller that can replace the model CB38M2B (IB) - 1

Loic691, 2024-06-11:
Hi
Too follow
I rece,tly bought a E7 pro and the hardware is a CB38M2L(IB)-2
Is this the same pinout ?
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

iMicknl, 2024-06-11:
@Loic691 it is easier to see if you open your control panel and show the PCB. You can join our Discord to discuss, but good to first do some efforts yourselves.

Loic691, 2024-06-11:
> @Loic691 it is easier to see if you open your control panel and show the PCB. You can join our Discord to discuss, but good to first do some efforts yourselves.

Well. I try to take photo of PCB this week end !

Closed 2023-02-04.

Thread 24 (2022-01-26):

ASR

DeastinY, 2022-01-26:
I've been using the ESPHome variant for a few days and today set up an automation to press M1 / M2 every 30 minutes. After some time it failed and the display showed "ASR".
Couldn't control anything with the ESP anymore and needed to attach the panel and move the desk all the way down to reset it.
Anyone already had similar issues? Something to expect to happen more often?

DeastinY, 2022-06-28:
I've encountered the issue so often that I stopped using it altogether :/
In the short time I tried to look into it I couldn't really get any information together, so I just stopped.
Willing to help if anyone wants to look into this though, if time permits.

xkisu, 2022-07-11:
I'm getting this frequently as well too, I've tried adjusting the esp home config a bit to cover what I thought where some edge cases with the cover but it hasn't helped.

Desk: PrimeCables PLUS+
Control Panel: Loctek HS01B-1

It seems to get stuck in the ASR/Reset mode any time I leave it and don't move the desk for several hours.

On a side note, I added a button component to reset it (but I've had intermittent success with wether it works or not, sometimes you hear the relay clicking to move the desk down but it doesn't actually move):
```yaml
button:
  ...
  - platform: template
    name: "Reset Desk"
    on_press:
      - while:
          condition:
            sensor.in_range:
              id: desk_height
              # When the desk is in ASR/Reset mode is appears to return an invalid height of 50cm.
              #
              # When this happens, the down button needs to be held until the desk lowers all the way
              # and the height resets to the correct minimum height.
              below: ${min_height}
          then:
            - logger.log: "Executing down command"
            - button.press: button_down
            - delay: 10ms
```

xkisu, 2022-07-11:
I noticed that my ESP was periodically rebooting it's self as I'm not using Home Assistant (using my own API client) and the [Native API Component](https://esphome.io/components/api.html) is setup to reboot the entire board after 15mins by default if a Home Assistant client hasn't connected.

I've disabled the automatic reboot to see if that improves the issue, I'm wondering if my modified ESP config pressing M button on boot every 15 minutes due to the restart is what's been causing it to happen frequently.

xkisu, 2022-07-12:
I made a few changes to the esphome config that seem to have fixed the ASR code repeatedly appearing, I've left it running for 48 hours and made constant height adjustments and haven't ran into it again, whereas previously it would happen every couple of hours.

Changes I made:
 * Fixed the board rebooting every 15 minutes due to no Home Assistant connection
 * Changed the UART switch components out for buttons that send a UART command, not sure if this was an improvement but it simplified some of my other automations
 * Raised the delay on opening/closing the cover to 250ms in case the controller was being overwhelmed, I noticed some odd behaviour when it was lower (like the desk "seizing" up, shaking, and not really moving) that's also stopped now that it's higher

One other thing I'm also going to add if the ASR code occurs again is toggling the "Virtual Screen" pin high/low on a timeout when buttons are pressed to simulate the actual behaviour I'm seeing on the controller in case the screen being alway on to the controller is problematic.

xkisu, 2022-07-18:
My ESPhome has been running for 5 days straight now with no issues and I haven't ran into the ASR code again, I think increasing the button delay on the cover to 250ms and fixing the board rebooting every 15 minutes definitely solved whatever was causing it to occur constantly.

DeastinY, 2022-08-22:
@xkisu did you publish your changes somewhere or could you point me to the changes you did in detail?
Cheers and thanks for apparently figuring out what was going on!

xkisu, 2022-08-22:
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

@DeastinY You've got it! I forgot to push, but those are the two changes I made that seem to have stabilized it long-term. I've been running it without issues over a month now after doing those two changes.

DeastinY, 2022-08-23:
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
While I can still see strange uptime behaviour in HA, it seems to work stable for me now too! Closing for now, thanks again @xkisu !

xkisu, 2022-08-23:
> 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
> While I can still see strange uptime behaviour in HA, it seems to work stable for me now too! Closing for now, thanks again @xkisu !

I'm getting that as well on my ESP8266! I'm not entirely sure why, but it seems to be something related to ESPHome and now anything to do with the desk script as far as I can tell 😀

DeastinY, 2022-08-26:
Happened again. Two days it was stable, now height is locked at 50cm and I need to reattach the control panel to change anything :/

KrX3D, 2022-09-25:
Hello, it seems "you" are pressing the M button to long. if it is pressed for 5 seconds (could also be 3 sec depending on your desk) your table enters Factory reset mode, id you go into this mode you need to move you table all the way down to finish resetting.

you could look at my config here. and if your tables does nothing with the 1+2 press comand you could change your code and use this switch and not the M button

https://github.com/iMicknl/LoctekMotion_IoT/issues/35

DeastinY, 2022-09-26:
Hi,
> "you"
why is this quoted 🤨?

> if it is pressed for 5 seconds (could also be 3 sec depending on your desk) your table enters Factory reset mode, id you go into this mode you need to move you table all the way down to finish resetting.

Explanation sounds good, but I'm not pressing the M button manually :/ Is this done automatically somewhere?

Cheers and thanks for the input!

DeastinY, 2022-09-27:
> hi, with "you" i meant some code, since you didnt post your full code i dont know what you changed.
>
> so maybe your code for pressing M1/M2 every 30 minites is the cause?

aaah, got it, thanks!
Hmm...
I'm just hitting the M1/M2 via automation same as I would in the UI, my code is unchanged from the original yaml:
```
  - platform: uart
    name: "Preset 1"
    id: switch_preset1
    icon: mdi:numeric-1-box
    data: [0x9b, 0x06, 0x02, 0x04, 0x00, 0xac, 0xa3, 0x9d]
    uart_id: desk_uart
```
I'll dig around, but not really sure it could be this

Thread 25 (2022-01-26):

Add support for HCB103A-1

Zeustopher, 2022-01-26:
I love the idea of this project and would love to have support added for the model HCB103A-1 controller. It appears that this is one of the newer models that they are using in several of their desks. What can I do to help get what is needed to add support for the HCB103A-1?

-------------

Example desks:
* https://www.amazon.com/Flexispot-Workstation-Ergonomic-Controller-Adjustable/dp/B07W8W8XKV/
* https://www.amazon.com/FLEXISPOT-Computer-Electric-Controller-Adjustable/dp/B08THG96PV/
* https://www.loctekmotion.com/Standing-Desks/Home-Solutions/ET119
* https://www.flexispot.com/height-adjustable-desks/seiffen-spliced-l-shaped-standing-desk-ef1l

I wasn't able to find the model listed on Flexispot's or LoctekMotion's websites.
An example desk with documentation for the HCB103A-1: https://www.flexispot.my/wp-content/uploads/2021/08/EF1-Manual.pdf

-------------

## Images

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
(The port shown to the right labeled as "HS" is the RJ45 port)

Floyer007, 2022-03-14:
I've a similar desk and want to see it in this project as well.

The control panel optically looks exactly the same but is HCB103A-2.
Board has the silkscreen: HCB103(HCB123)_V7(main)

What I figured out so far.
MCU is STM8L151 C8T6

**RJ45**
- Pin 7 - GND

**Four Pin on side**
1. STM Pin 1 - PA0 - SWIM - USART1
2. STM Pin 2 - PA1 - NRST
3. GND
4. VCC (STM Pin 10,11,12)

Floyer007, 2022-03-15:
Well, I created a adapter to breakout the RJ45 to 2.54mm THT Headers and checked the signals with my oscilloscope.
I haven't seen usefull signals on the pins. All tested while moving the desk up and down.

1. to 4. 50mV 50Hz signal -> Noise
5. Steady 5.48V rail
6. Steady 2.7V rail
7. GND
8. Steady 5.74V rail

I will check the four-pin port in the next days.

Zeustopher, 2022-03-15:
@Floyer007 thanks for the help on this. I hope we can come up with something. I had kicked around the idea of just soldering some wires onto the push buttons and doing it that was also, but its just nowhere near as elegant.

Floyer007, 2022-03-15:
Would at least be easier/cleaner on yours, as they use a FPC-cable in my version now:

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

Floyer007, 2022-03-15:
After checking again [HS01B-1](https://github.com/iMicknl/LoctekMotion_IoT#hs01b-1) could fit.
GND [7] is at the right place and 5V [8] (5.7V actally from a internal 3.5A DC-DC converter) as well.

Pin 6 can be routet over D19 and Q5 to STM-Pin 41 (PC2, actually RX).
I wasn't able to trace the other signals on the board.

Setting Pin 4 to 5V didn't initiated a data output nor turned the display on.
Have to try the mentioned [WakeUp Command](https://github.com/iMicknl/LoctekMotion_IoT#retrieve-current-height)

Floyer007, 2022-03-16:
Sadly there is no output on the potential RX and TX pins. (Tried with two serial adapters at my PC via hterm)

- WakeUp command (0x9b 06 02 00 00 6c a1 9d) has no effect
- Reversed coommand (0x9d a1 6c 00 00 02 06 9b) has no effect
- RX, TX switched has no effect

Currently I assume the port is deactivated completely.

Also there is no output on Pin 1 and 2 of the side port.

schmic, 2022-10-19:
I have the same thing as @Floyer007 and found out that the RJ45 was supposed to carry a Bluetooth dongle.

https://fccid.io/2ARK8-BTD02

I tried to fiddle around with an ESP8266 but could not get anything to work, maybe one of you guys can figure out some more information about the BT dongle.

schmic, 2022-10-19:
https://fccid.io/2ARK8-BTD02/Internal-Photos/Internal-Photos-4694579

This should be the interesting part cause it shows the cables for 5V, G, TX & RX.

Floyer007, 2022-10-20:
The Pinout of this dongle just proves [HS01B-1](https://github.com/iMicknl/LoctekMotion_IoT#hs01b-1).
It shows a permanent connection between Pin8 and Pin4.

**Bluteooth-Dongle Pinout**
1 -
2 -
3 (wh) SWS
4 (rd) 5V-SW -> Permanent to +5V
5 (gr) RX-1
6 (sw) TX-1
7 (bl) GND
8 (ye) +5V

Now this dongles protocol would be interesting.
Do you know if it can be purchased somewhere?

schmic, 2022-10-20:
All I found was this video: https://www.facebook.com/Flexispot-FR-103607731866634/videos/cool-avec-un-bluetooth-vous-pouvez-r%C3%A9gler-lhauteur-de-votre-bueau-flexispot-sur-/366861188944567/

No place to buy one of those though (yet).

Floyer007, 2024-03-19:
Hi guys,

I just had this project in mind again and tried the new ESPHome method, but it did not work as well.

So I gave up using the serial interface and did it the classical way.

I utilized the free space, where no components are placed for a second motor.
Everything got isolated with Koptan tape and a Raspberry Pi Pico W placed onto it.
As I learned the hard way, the plastic housing might press the BOOTSEL button. So keep the Pico away of the side of the housing.
The Pico W was choosen, as it's compatible with ESPHome and has a lot of IO, which might be usefull in the future to decode the display as well.

The original plan was to just connect the buttons to GPIOs and use the Picos open-drain to pull them down and press the buttons.
Turns out either the Pico does not support open-drain or ESPHome has issues setting it...

Therefore I choose nFETs (BS170) from an old project to pull the buttons to GND.
Source connected to GND, Gate to a GPIO and Drain via a wire to the resistors next to the buttons.
It does not look nice, but does it's job.
The signals should also be available on R1 and R2 on the main PCB, too.

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

Here is the used ESPHome code I used.
I utilizes the secret functionality:
```
esphome:
  name: flexispot
  friendly_name: flexispot

rp2040:
  board: rpipicow
  framework:
    # Required until https://github.com/platformio/platform-raspberrypi/pull/36 is merged
    platform_version: https://github.com/maxgerhardt/platform-raspberrypi.git

############################
# Enable logging
logger:

# Enable Home Assistant API
api:
  encryption:
    key: !secret api_encryption_key

ota:
  password: !secret ota_password

wifi:
  ssid: !secret wifi_ssid
  password: !secret wifi_password
  fast_connect: true

  # Enable fallback hotspot (captive portal) in case wifi connection fails
  ap:
    ssid: "Flexispot Fallback Hotspot"
    password: !secret fallback_password

time:
  - platform: sntp
    id: sntp_time
    servers:
      - !secret ip_sntp

#captive_portal:

# Not supported on Pico W
#web_server:
#  port: 80

############################
switch:
  - platform: gpio
    id: button_up
    name: "Up"
    icon: "mdi:arrow-up-bold-box"
    pin:
      number: 21
      inverted: false
      mode: OUTPUT

  - platform: gpio
    id: button_down
    name: "Down"
    icon: "mdi:arrow-down-bold-box"
    pin:
      number: 20
      inverted: false
      mode: OUTPUT

  - platform: gpio
    id: button_m1
    name: "M1"
    icon: "mdi:numeric-1-box"
    pin:
      number: 19
      inverted: false
      mode: OUTPUT
    on_turn_on:
    - delay: 500ms
    - switch.turn_off: button_m1

  - platform: gpio
    id: button_m2
    name: "M2"
    icon: "mdi:numeric-2-box"
    pin:
      number: 18
      inverted: false
      mode: OUTPUT
    on_turn_on:
    - delay: 500ms
    - switch.turn_off: button_m2

  - platform: gpio
    id: button_m3
    name: "M3"
    icon: "mdi:numeric-3-box"
    pin:
      number: 17
      inverted: false
      mode: OUTPUT
    on_turn_on:
    - delay: 500ms
    - switch.turn_off: button_m3

  - platform: gpio
    id: button_m4
    name: "M4"
    icon: "mdi:numeric-4-box"
    pin:
      number: 16
      inverted: false
      mode: OUTPUT
    on_turn_on:
    - delay: 500ms
    - switch.turn_off: button_m4

```

I hope this gives inspiration and/or helps.

ArthFink, 2024-04-28:
I have tried @Floyer007 approach with an esp d1 Mini, and got it to work without nFETs, not all pins on the esp work, or the connection that I soldered is bad. But I was fine with only having 2 memory buttons and Up and Down.

``` yaml
switch:
  - platform: gpio
    name: "Position 1"
    icon: mdi:chair-rolling
    id: button_m1
    pin:
      number: D2
      inverted: True
      mode:
        output: True
        open_drain: True
    on_turn_on:
    - delay: 500ms
    - switch.turn_off: button_m1

  - platform: gpio
    name: "Down"
    icon: "mdi:arrow-down-bold-box"
    id: button_down
    pin:
      number: D3
      inverted: True
      mode:
        output: True
        open_drain: True

  - platform: gpio
    name: "UP"
    icon: "mdi:arrow-up-bold-box"
    id: button_up
    pin:
      number: D4
      inverted: True
      mode:
        output: True
        open_drain: True

  - platform: gpio
    name: "Possition 4"
    icon: mdi:human-handsup
    id: button_m4
    pin:
      number: D6
      inverted: True
      mode:
        output: True
        open_drain: True
    on_turn_on:
    - delay: 500ms
    - switch.turn_off: button_m4

   ```

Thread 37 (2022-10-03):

Support request for model HCB213A-1

lboue, 2022-10-03:
Hello,

The HCB213A-1 model does not appear on the supported models page.
Here is a picture below:

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

Regards

horriblenoises, 2022-10-21:
I just got an [EN1B desk frame off amazon](https://www.amazon.com/dp/B07GWCSXJ8) (in the US) with this model controller and connected a D1 mini to it with the ESPhome instructions and the e5b yaml file. It required minimal modifications (min/max height adjustment & adding preset 4) but I'm very happy to say it seems to work really well. Cover up/down travel the desk to min/max, the presets all work, and the height readout is correctly displayed in Home Assistant.
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

renjithstalin, 2023-01-24:
@horriblenoises Can you please share your preset 4 entry? also, does down button work for you? Thanks in advance

horriblenoises, 2023-01-25:
@renjithstalin

Sorry. I got distracted from this project for a bit. Never added the problems I'd found after posting that. It seems like the up/down buttons don't work after a timeout occurs. Pin20 doesn't seem to wake it either. So I changed up/down to internal in the esphome yaml. My D1 mini also reboot a lot after a command is finished. I have to investigate if it's something I've done or something that isn't compatible.

This aside, it does work as well as I need it to. The preset buttons are not effected by the timeout issue so I set P1 to min, P4 to max, and if I need granularity beyond that, I can always add an automation to Home Assistant or the ESP to call for specified heights (send button press P4; if height = height requested -1, send button press P4 again to stop).

```
  - platform: uart
    name: "Preset 1"
    id: ${device_name}_preset1
    icon: mdi:numeric-1-box
    data: [0x9b, 0x06, 0x02, 0x04, 0x00, 0xac, 0xa3, 0x9d]
    uart_id: desk_uart

  - platform: uart
    name: "Preset 2"
    id: ${device_name}_preset2
    icon: mdi:numeric-2-box
    data: [0x9b, 0x06, 0x02, 0x08, 0x00, 0xac, 0xa6, 0x9d]
    uart_id: desk_uart

  - platform: uart
    name: "Preset 3"
    id: ${device_name}_preset3
    icon: mdi:numeric-3-box
    data: [0x9b, 0x06, 0x02, 0x10, 0x00, 0xac, 0xac, 0x9d]
    uart_id: desk_uart

  - platform: uart
    name: "Preset 4"
    id: ${device_name}_preset4
    icon: mdi:numeric-4-box
    data: [0x9b, 0x06, 0x02, 0x00, 0x01, 0xac, 0x60, 0x9d]
    uart_id: desk_uart

  - platform: uart
    name: "Up"
    id: ${device_name}_up
    icon: mdi:arrow-up-bold
    data: [0x9b, 0x06, 0x02, 0x01, 0x00, 0xfc, 0xa0, 0x9d]
    uart_id: desk_uart
    internal: true

  - platform: uart
    name: "Down"
    id: ${device_name}_down
    icon: mdi:arrow-down-bold
    data: [0x9b, 0x06, 0x02, 0x02, 0x00, 0x0c, 0xa0, 0x9d]
    uart_id: desk_uart
    internal: true
```

renjithstalin, 2023-01-25:
Many thanks for the response. I have managed to get Preset 4 working. But my down button still doesn't work. I'm going to try this with esp32 and see if it works. And yes, my wemos d1 mini reboots too :(
Thanks again.

sebPomme, 2023-02-07:
> It seems like the up/down buttons don't work after a timeout occurs.

I read somewhere on another model that UP/DOWN work only if the panel light are turn on before :thinking: so the trick was to send an impulsion to a pin that are link to the screen before doing an action .
I c'ant remember where.

May we can apply the same pattern.

lourdrivera123, 2023-05-02:
> Many thanks for the response. I have managed to get Preset 4 working. But my down button still doesn't work. I'm going to try this with esp32 and see if it works. And yes, my wemos d1 mini reboots too :( Thanks again.

Were you able to test it on esp32?
We have the same model of control panel, but I don't know how to map it correctly with my RJ45 and ESP32 Devkit V1.

ThomDietrich, 2023-10-06:
Hey guys, thanks for confirming that it works for the HCB213A-1. I bought the desk "Sanodesk EC4 "EC4B-EU and it came with the controller box HCB2**2**3A-1. I expect it to be identical, except for the two-motor-drive. I'll try with the e5b yaml and an esp32 the next couple of days.

For who might find it useful, here are some pictures of the controller:

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

ThomDietrich, 2023-10-06:
Couldn't wait 😄

I've quickly thrown together an RJ45 to ESP32 cable and flashed the firmware. I can confirm that everything is working. This includes the up and down commands - no wake-up or PIN20 needed (both of those seem to have no effect on my specific device).

The only bug I found is that "Desk Height" stays unknown after the ESP boots up. This can be resolved via a wake-up (display or programmatically) and isn't a bigger issue for my use cases. Still, I found another workaround for waking up the device: If a preset button is not programmed to a specific height, it will wake up the display but won't move the desk.

iMicknl, 2023-10-06:
@ThomDietrich would you be willing to test https://github.com/iMicknl/LoctekMotion_IoT/issues/67? Hopefully this will also solve your issues.

Zagur, 2024-01-18:
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

I currently have an HCB213A-1 and I was testing with the configuration for e5b with what you have mentioned. I am using an ESP328266 Mod, what scheme should I follow to connect the cables correctly?

ThomDietrich, 2024-01-18:
Hey @Zagur, you should find everything you need in https://github.com/iMicknl/LoctekMotion_IoT/issues/67

Zagur, 2024-01-19:
First of all I want to thank everyone for this incredible project.

I have been reading several issues and have configured my ESP32 2866 to control the HCB213A-1 controller. Everything seems to be working correctly except for one thing I've seen in Home Assistant.

When I try to set the height to 90cm it always adds between 2 and 2.7cm extra. I use the mushroom-number-card to show the height but it doesn't work very well. A value is always set below or above what is indicated.

Doing some tests I get some ideas/doubts:

- Would it be possible that the switch_up and switch_down, instead of going up to the maximum or minimum, did it in 5 at a time or 10 at a time? (maybe put a parameter to configure this).

Regards!

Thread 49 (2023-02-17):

Commands dont execute unless i wake desk from control panel CB38M2L(IB)-1 and HS01B-1

briodan, 2023-02-17:
i'm running this on an ESP8266 D1 mini and i'm running into an issue where the commands don't execute unless I wake the desk from a physical control button. After waking the desk from a physical button i get less then 10 seconds to execute a command from the ESP before it goes unresponsive

The ESP8266 is connected via the second RJ45 port, while the HS01B-1 panel is connected to the first port.

here is my config

```
substitutions:
  device_description: ESP8266 Custom
  friendly_name: desk
  name: desk
  min_height: "62.6" # Min height + 0.1
  max_height: "127.9" # Max height - 0.1

esphome:
  name: ${name}
  comment: ${device_description}
  platform: ESP8266
  board: d1_mini
  includes:
    - desk_height_sensor.h
  on_boot:
    priority: -10
    then:
      - switch.turn_on: switch_m

# Enable logging
logger:

# Enable Home Assistant API
api:
  encryption:
    key: !secret api_key

ota:
  safe_mode: true
  password: !secret ota_password

wifi:
  ssid: !secret wifi_ssid
  password: !secret wifi_password

  # Enable fallback hotspot (captive portal) in case wifi connection fails
  ap:
    ssid: "${friendly_name} Fallback Hotspot"
    password: !secret fallback_password

captive_portal:

web_server:
  port: 80

uart:
  - id: desk_uart
    baud_rate: 9600
    tx_pin: D5
    rx_pin: D6

sensor:
  - platform: wifi_signal
    name: "${friendly_name} WiFi Signal"
    update_interval: 60s

  - platform: uptime
    name: Uptime

  - platform: custom
    lambda: |-
      auto desk_height_sensor = new DeskHeightSensor(id(desk_uart));
      App.register_component(desk_height_sensor);
      return {desk_height_sensor};
    sensors:
      id: "desk_height"
      name: Desk Height
      unit_of_measurement: cm
      accuracy_decimals: 1
      icon: "mdi:counter"

button:
  - platform: restart
    name: "${friendly_name} Restart"

switch:
  - platform: gpio
    name: "Virtual Screen"
    pin:
      number: D2
      mode: OUTPUT
    restore_mode: ALWAYS_ON
    internal: true

  - platform: uart
    name: "${friendly_name} Preset 1"
    id: switch_preset1
    icon: mdi:numeric-1-box
    data: [0x9b, 0x06, 0x02, 0x04, 0x00, 0xac, 0xa3, 0x9d]
    uart_id: desk_uart

  - platform: uart
    name: "${friendly_name} Preset 2"
    id: switch_preset2
    icon: mdi:numeric-2-box
    data: [0x9b, 0x06, 0x02, 0x08, 0x00, 0xac, 0xa6, 0x9d]
    uart_id: desk_uart

  - platform: uart
    name: "${friendly_name} Preset 3"
    id: switch_preset3
    icon: mdi:numeric-3-box
    data: [0x9b, 0x06, 0x02, 0x10, 0x00, 0xac, 0xac, 0x9d]
    uart_id: desk_uart

  - platform: uart
    name: "${friendly_name} Up"
    id: switch_up
    icon: mdi:arrow-up-bold
    data: [0x9b, 0x06, 0x02, 0x01, 0x00, 0xfc, 0xa0, 0x9d]
    uart_id: desk_uart
    internal: true

  - platform: uart
    name: "${friendly_name} Down"
    id: switch_down
    icon: mdi:arrow-down-bold
    data: [0x9b, 0x06, 0x02, 0x02, 0x00, 0x0c, 0xa0, 0x9d]
    uart_id: desk_uart
    internal: true

  - platform: uart
    name: "${friendly_name} M"
    id: switch_m
    icon: mdi:alpha-m-circle
    data: [0x9b, 0x06, 0x02, 0x20, 0x00, 0xac, 0xb8, 0x9d]
    uart_id: desk_uart

  - platform: uart
    name: "${friendly_name} (wake up)" # Not available on all control panels
    id: switch_wake_up
    icon: mdi:gesture-tap-button
    data: [0x9b, 0x06, 0x02, 0x00, 0x00, 0x6c, 0xa1, 0x9d]
    uart_id: desk_uart

cover:
  - platform: template
    # icon: mdi:table-chair
    # icon: mdi-human-male-height-variant
    name: "${friendly_name}"
    assumed_state: true

    # Move desk up
    open_action:
      - while:
          condition:
            sensor.in_range:
              id: desk_height
              below: ${max_height}
          then:
          - logger.log: "Executing up command"
          - switch.turn_on: switch_up
          - delay: 10ms

    # Move desk down
    close_action:
      - while:
          condition:
            sensor.in_range:
              id: desk_height
              above: ${min_height}
          then:
          - logger.log: "Executing down command"
          - switch.turn_on: switch_down
          - delay: 10ms
    optimistic: true
```

log sample from the logs of executing a command and nothing happening
```
15:33:43 | [D] | [sensor:126] | 'desk WiFi Signal': Sending state -59.00000 dBm with 0 decimals of accuracy
15:33:46 | [D] | [switch:013] | 'desk Preset 3' Turning ON.
15:33:46 | [D] | [switch:056] | 'desk Preset 3': Sending state ON
15:33:46 | [D] | [uart.switch:020] | 'desk Preset 3': Sending data...
15:33:46 | [D] | [switch:056] | 'desk Preset 3': Sending state OFF
15:33:56 | [D] | [sensor:126] | 'Uptime': Sending state 423.09698 s with 0 decimals of accuracy
15:34:43 | [D] | [sensor:126] | 'desk WiFi Signal': Sending state -60.00000 dBm with 0 decimals of accuracy
15:34:56 | [D] | [sensor:126] | 'Uptime': Sending state 483.09698 s with 0 decimals of accuracy
15:35:43 | [D] | [sensor:126] | 'desk WiFi Signal': Sending state -59.00000 dBm with 0 decimals of accuracy
15:35:56 | [D] | [sensor:126] | 'Uptime': Sending state 543.09802 s with 0 decimals of accuracy
15:36:43 | [D] | [sensor:126] | 'desk WiFi Signal': Sending state -60.00000 dBm with 0 decimals of accuracy
15:36:56 | [D] | [sensor:126] | 'Uptime': Sending state 603.09698 s with 0 decimals of accuracy
15:37:43 | [D] | [sensor:126] | 'desk WiFi Signal': Sending state -60.00000 dBm with 0 decimals of accuracy
15:37:56 | [D] | [sensor:126] | 'Uptime': Sending state 663.09900 s with 0 decimals of accuracy
15:38:43 | [D] | [sensor:126] | 'desk WiFi Signal': Sending state -59.00000 dBm with 0 decimals of accuracy
```

iMicknl, 2023-02-18:
Did you follow the instructions and did you connect and turn PIN20 on or off?

briodan, 2023-02-19:
ok now i feel like and idiot turns out there was a loose connection on one of the pins that would slip into place everytime i pushed the button on the control panel.

Closed 2023-02-19.

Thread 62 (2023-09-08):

ESP won't boot up with keypad connected

formatBCE, 2023-09-08:
Maybe someone already had this problem:
My device works really good, everything is supported. I power it from 5v cord of the table controller.
However, if i pull the table plug out and put it back in, ESP won't boot, if keypad was connected to RJ45 socket...
So i need to pull keypad out of the device, reset ESP and put it back again after 5-6 seconds. And even then, sometimes ESP blinks and stops responding - today, for example, it took me 4 tries to put it back to work with keypad connected.

Is it something related to the power? I checked all connected pins, and they shouldn't prevent ESP from starting, according to docs...

formatBCE, 2023-10-11:
So from my findongs, "Pin20" contact has 5v (actually 4.7) on it. Not safe to use directly with ESP32 GPIO (although might work for some time, but can eventually break the chip). I tried to build small voltage divider on that, but it doesn't work as well.
At current time i'm out of ideas, and can't understand why i'm the only one with this trouble.

If i don't connect Pin20 from keypad to ESP, it boots up normally - but nothing works, operations don't take any effect.

I tried 2 different boards, with as clean config as i could: NodeMCU ESP32, and ESP32-MINI boards. Have same results on both.

BCould it be, that my desk keypad is somehow different? It's Flexispot E5.

formatBCE, 2023-10-11:
Here's full thread of my lurkings - i actually tried a lot of stuff:
https://www.reddit.com/r/esp32/comments/1742yoa/comment/k4anb0z/

iMicknl, 2023-10-11:
@formatBCE what is your pin-out? Have a look at https://github.com/iMicknl/LoctekMotion_IoT/issues/67.

In theory most ESP32's should be tolerant to 5V.

formatBCE, 2023-10-11:
@iMicknl according to data sheets, they aren't. Max allowed voltage on GPIO is 3.6-3.9V depending on board, if the specific board has no special voltage handling included. By docs, it MIGHT work for some time, but is dangerous long-term.

My pinout is according to that Reddit post, here's the image: https://www.reddit.com/media?url=https%3A%2F%2Fi.redd.it%2Fy5d1kf1ar8tb1.png

I tried different pins yesterday for both UART and PIN20, behaviour is unchanged.

iMicknl, 2023-10-11:
@formatBCE the pinout on your image is hard to read. Should I read it as pin 1 to 8 (from top to bottom) on your desk controller and keypad? Please have a look at my link and try the other pin-out.

Regarding 5V tolerance, I have to say this is quite a mess. There are not many official sources. https://hackaday.com/2016/07/28/ask-hackaday-is-the-esp8266-5v-tolerant/ describes a bit (with sources), but no official statement. In my own tests, I had issues with ESP8266 and with ESP32 it has been solved.

formatBCE, 2023-10-11:
Color			What	Desk->ESP		ESP->Control		Desk->Control

Brown			VCC		VCC 							+
White-brown		GND	GND							+
White-blue		RX		GPIO16							+
Green			TX		GPIO17			GPIO26
Blue				Pin20	GPIO23			GPIO22

Maybe this is better? All other colors from controller are going directly to keypad.
It's actually default pinout. Also i tried with GPIO18 instead of GPIO26, and GPIO27 instead of GPIO22. Same behaviour.

formatBCE, 2023-10-11:
@iMicknl updated my comment. Freaking Github and its markdown :)

iMicknl, 2023-10-11:
Haha, makes sense. If I am not mistaken, your pin-out is still different than the one mentioned in https://github.com/iMicknl/LoctekMotion_IoT/issues/67? Or did you start counting in reverse?

Have you tried with my config, without your desk keypad connected? So no pass through.

formatBCE, 2023-10-11:
@iMicknl you're right, i started in reverse... Looked on wrong table in README. yeah it's 8->7->...->4.
Will try with no passthrough now.

iMicknl, 2023-10-11:
Thanks! And please try with my new YAML as well. I have been running this for a long time and it is stable, especially compared to previous versions.

formatBCE, 2023-10-11:
@iMicknl tried with your config and replaced sensor file code just in case.
It works, without keypad. (Not mentioning some weirdness because my desk height is in inches, and some buttons are screwed too.

iMicknl, 2023-10-11:
Thanks! What is different for a desk that uses inches? Is changing the numbers (and unit just for visual purposes) not enough?

formatBCE, 2023-10-11:
Yeah, min/max height, units - that's it :)

formatBCE, 2023-10-11:
@iMicknl frankly saying, it wasn't giving me troubles to rule the desk without passthrough before. Just needed to set PIN20 to always on - (virtual screen that is).

But the best thing would be to have keypad also working. :)

formatBCE, 2023-10-24:
Alright, i unplugged pin20 cable, that is going from keypad to ESP, and, using your new code from #67 it works now, no hanging on reboot. Will try it a bit more, but looks like it's working. I guess i will have to live without child lock, but it's alright.

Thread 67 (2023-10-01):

[Testers wanted] New ESPHome configuration and documentation improvements

iMicknl, 2023-10-01:
I am working on improving this repository. The main goal is to make it easier to get started, by providing only two configurations and a more updated README + configuration. In order to achieve this, all feedback and contributions are welcome.

**Main goal:**
- [ ] Only provide 2 options and pin-outs (LoctekMotion Desk and LoctekMotion Desk with pass through)
- [ ] Advise to use ESP32 due to 5V tolerance and hardware UART, add note about ESP8266 with voltage shifter (5V -> 3.3V).
- [ ] Simplify the README and installation instructions (add a version for non technical people, 'plug and play')
- [ ] Add system diagrams explaining the wiring
- [x] Modernize YAML config with cover, buttons and number entity
- [x] Remove the need for `desk_height_sensor.h` (load from custom component)
- [ ] Simplify and improve docs (e.g. add https://esphome.io/guides/getting_started_hassio.html)

**Long term**:
- [ ] Use ESPWebtools (https://esphome.github.io/esp-web-tools/) to make it easier to get started

## Changes
- Switch will turn off automatically when min or max height is reached
- New cover entity
- New number entity (still buggy)
- Presets are exposed as button entities
- Experimental buttons for alarm / alarm off

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

## Pin-out
In the past we have discussed multiple pin-outs, but it seems that multiple pin-outs can be supported by the same desk.

| RJ45 pin | Name      |  ESP32 |
| -------- | --------- | --------- |
| 8        | +5V (VDD) |  VIN |
| 7        | GND       | GND |
| 6        | TX        | TX2 (GPIO17) |
| 5        | RX        |  RX2 (GPIO16) |
| 4        | PIN 20    | D23 (GPIO23) |
| 3        | (unknown) |  |
| 2        | SWIM      | |
| 1        | RES       | |

You can change the ESP32 pin-out mapping, but don't forget to change the pin number in the YAML.

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
My setup, no soldering required.

## Configuration
[office-desk-esp32.yaml](https://github.com/iMicknl/LoctekMotion_IoT/blob/v2/packages/office-desk-esp32.yaml)

The following secrets should be part of your ESPHome config: `encryption_key`, `wifi_ssid` and `wifi_password`.

## Feedback
Any feedback and contributions are welcome! For example the work above adopted for pass through configurations.

ThomDietrich, 2023-10-06:
Hey @iMicknl,

thanks for providing this updated version of the code. The improvements look really good but I did barely test them. First observations:

- You have mixed up preset 3 and 4 in the comments. On my device this is Button 4: https://github.com/iMicknl/LoctekMotion_IoT/blob/6303fa7d10fc1cc102740a4a41e9dff448cd5c42/packages/office-desk.yaml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
- On my specific device the wake screen command and the PIN20 method do not work, however, "child lock" (which seems not supported) wakes up the device (and produces the current desk height) - so thank you!
- `update_interval: 0ms # update in every loop() iteration` in number "Desk Height" does what you intended, but is that really necessary?

General comment: It seems like more and more devices will be potentially supported by your project, and each will have their own caveats. My HCB223A-1 seems to be a good example. Should we capture those differences in a table of sorts?

brumouta, 2023-10-07:
Where one gets a board like that one you showed (rj45 connector with pins)?

Thanks

iMicknl, 2023-10-08:
Thanks a lot for your extensive feedback, @ThomDietrich!

> On my specific device the wake screen command and the PIN20 method do not work, however, "child lock" (which seems not supported) wakes up the device (and produces the current desk height) - so thank you!

The wake command does not work here as well. What do you mean with PIN20 doesn't work? PIN20 is set to `ALWAYS_ON` (high) to allow the ESP32 to control the desk.

>update_interval: 0ms # update in every loop() iteration in number "Desk Height" does what you intended, but is that really necessary?
This floods the log indeed, and I need to have a better look here. It needs to be at least 0.5s, in order for the number template to be updated with the height of the desk height sensor.

> A preset button will send the desk on its way. This can be stopped by e.g. shortly pressing the Up or Down button. Could you add a "Stop" button?
Good one! Perhaps we could make the cover.stop button behave like this. I am not sure how often you want to cancel a preset command?

> A binary_sensor that indicates that the desk is currently moving would be great
In theory the `cover` entity should have such a status already. We need to have a look if this is currently missing and if so, if this could be added.

> You've used the name "Desk Height" twice. Yes not a technical issue, more of an intuitive ick

Do you have any suggestions for a better name / structure? The issue here is that one is a sensor and the other one is a number entity (that is still a bit buggy).

ThomDietrich, 2023-10-09:
> PIN20 is set to ALWAYS_ON (high) to allow the ESP32 to control the desk.

Oh! I didn't know that. Compare here: https://github.com/iMicknl/LoctekMotion_IoT#execute-a-command
Maybe you want to add a description to the README? I wouldn't know because on my device the pin does not have a purpose, i.e., `ALWAYS_OFF` does not change any behavior.

> It needs to be at least 0.5s, in order for the number template to be updated with the height of the desk height sensor.

I get that. My first thought was a delta/throttle filter but glad I tested it: Filters are only supported by sensors. One option i can think of is to disable direct updates and do the following:

```yaml
      id: "desk_height"
      on_value:
        then:
          - component.update: set_desk_height
```

I've tested the solution and it works as expected.

>  I am not sure how often you want to cancel a preset command?

Probably very seldom but to me it feels like this action is missing from the options offered in HA. I would expect the Stop button to stop all movements, be it preset or cover actions. Yes the cover has this function but I generally like to offer slightly redundant but purposeful options. Makes integration in e.g. automations or a Lovelace dashboard a lot easier.

> In theory the cover entity should have such a status already. We need to have a look if this is currently missing and if so, if this could be added.

I thought so as well but doesn't seem like it 🧐 Anyhow, for the same reasons as above, I'd vote for a dedicated binary_sensor.

>  Do you have any suggestions for a better name / structure?

Good challenge. Nope can't think of one. Let's leave as is.

jamesmyatt, 2023-10-09:
BTW, ESP8266 is also tolerant to 5V inputs. e.g. https://www.tablix.org/~avian/blog/archives/2022/05/a_footnote_about_esp8266_5v_tolerance/

iMicknl, 2023-10-09:
> Oh! I didn't know that. Compare here: https://github.com/iMicknl/LoctekMotion_IoT#execute-a-command
Maybe you want to add a description to the README? I wouldn't know because on my device the pin does not have a purpose, i.e., ALWAYS_OFF does not change any behavior.

Interesting. So in your case you don't have PIN20 connected to your ESP + no PIN20 in your config?

Thanks for your other improvements, I will give it a try and update the startpost when I am done.

>BTW, ESP8266 GPIO pins are also tolerant to 5V inputs. e.g. https://www.tablix.org/~avian/blog/archives/2022/05/a_footnote_about_esp8266_5v_tolerance/
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
1100101, 2024-01-04:
I don't have Home Assistant, but I added an MQTT command to toggle the PIN20 switch.
If i toggle the switch off for at least 2 seconds, and then on again, the height data packages are being processed (I enabled the debug logging in `height_sensor.h`), and if the hight has changed it is being published.
But if I don't "touch" the virtual switch, and change the height of the table, no debug messages regarding height are being processed.

voydz, 2024-02-15:
Thanks for this project. I really appreciate the work that has been done.

Just as a note. I had to download the height sensor C implementation and use it with 'includes:' as the 'external_components:' entry does not work for me. (compile error)
Am I missing something?

I have the same issues with the reporting of the desk height. (Two RJ45 ports that seem to report different things.)
Will do some testing and share my findings if I got something interesting.

best regards

fbloemhof, 2024-03-09:
Seems to work fine!

My control box is a "CB38M3B(IB)-1". I found out my ethernet wiring is the other way around, but this might be my own fault. I only have RX/TX connected now and all looks good. If I use the original controller it also updates the esp status.

I am unable to power the ESP32 via the desk for now, might be this issue: https://github.com/esphome/issues/issues/4864. Will look into this later.

How can I add a preset and is it possible to adjust the alarm (timer)?

Also I would like to change the behavior of the up and down buttons to "momentary", the same as the desk itself. Would this be possible?

gschmidl, 2024-03-12:
I tried this on my standing desk with the HS13A-1 controller and a second RJ45 port and it worked instantly - what took the longest was getting the ESP32 into flash mode.

jamesmyatt, 2024-03-22:
Is this the same as the version in the v2.1 branch, which looks like it's the latest? https://github.com/iMicknl/LoctekMotion_IoT/tree/v2.1

markuspi, 2024-03-27:
Using my own esphome configuration, i got my Flexispot E7 stuck in `ASR` and `E07`  errors. Resolving the problem via esphome did not work right away: Continuously sending the _move down_ command using an interval of 100ms resulted in slow, jerky motion and did not fix the error. Only after i adjusted the `send_every`  interval down to 50ms, i was able to move the table down normally and fix the error

bobtheshizocat, 2024-03-31:
Thanks for the repository @iMicknl, and the helpful comments from everyone to read through!

I have a Flexispot E7 with the control box `CB38M2E(IB)-1` and the control panel `HS13B-1`. I'm using an `ESP32-WROOM-32` dev board (esp32dev) for the smart addon. This is my wiring (using the same one mentioned [here](#issuecomment-1763439839)):

| ESP32         | Cable-Color | RJ45-PIN |
|---------------|-------------|----------|
| +5V (VIN)     | Brown       | 8        |
| GND           | White-Brown | 7        |
| GPIO16 (RX2)  | White-Blue  | 5        |
| GPIO23        | Blue        | 4        |
| GPIO17 (TX2)  | Green       | 2        |
<details>
  <summary>Click here to expand for an image of the wiring</summary>
  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
</details>

**Does work as expected:**
- [x] Desk (Up- / Down- / Stopbutton has a short delay)
- [x] Alarm
- [x] Preset 1
- [x] Preset 2
- [x] Sit
- [x] Stand
- [x] Desk Height (Sensor)
- [x] Alarm off
- [x] Child Lock
- [x] Memory
- [x] Restart

**Doesn't work as expected:**
- [ ] Desk Height (Number): Shows the current height, but if I enter a value, it sets the desk either too high while going up or sets it too low while going down.
- [ ] Wake Screen: Doesn't work.

dominik-b13, 2024-04-02:
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

i solved the compile error by using an older esphome version (2023.6.5 worked for me, didnt test any newer)

Qu4ndo, 2024-04-17:
I have a **Flexispot E7 Pro** and built it using a **NodeMCUv2 Board (ESP8266)**.
The pin-out worked as expected but I had to lookup my specific wiring diagram for the used ethernet cables (B standard).
After also changing the pins to the correct ones on my NodeMCUv2 board (including changing it in the esphome yaml) everything worked right out of the box!

**NodeMCUv2 Mapping:**

| RJ45 pin | Name | ESP32 |
| ------------- | ------------- |------------- |
| 8 | +5V (VDD) | VIN |
| 7 | GND | GND |
| 6 | TX | TX (GPIO1) |
| 5 | RX | RX (GPIO3) |
| 4 | PIN 20 | D7 (GPIO13) |
| 3 | (unknown) | |
| 2 | SWIM| |
| 1 | RES| |
<br>

**Additional Notes:**
- **Don't forget to place the file "desk_height_sensor.h" into your esphome
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

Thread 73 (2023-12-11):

FlexiSpot Q8 "Comhar Pro" w/ controller HCB215C-4

mcomer-captech, 2023-12-11:
I just bought this desk and would like to implement some control / automation. This controller is a single unit with motor controls and display integrated.

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

Internally the primary PCB is identified as HCB115C-1.

It does have a single RJ45 along with power in, two motors, and a DC-out for wireless charging and a board-edge connector which has a cover on it:

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

Any thoughts on this one? I have an oscilloscope w/ login analyzer and can do some research and digging here on my own also. I did create a little breakout cable from the RJ45 and did identify ground and +5v, but everything else appears to be floating or ground with a little bit of switching / motor noise. I suspect I may need to do something to "wake up" this interface, e.g. the "pull a pin high" (pin 20 thing) and/or wake-up command I've seen referenced elsewhere - but hard to do that without some kind of pinout.

I would love some suggestions on how to get started here and will of course share all of my findings back with the community.

iMicknl, 2023-12-11:
Thanks for your extensive post! You could try starting with the following pin-out: https://github.com/iMicknl/LoctekMotion_IoT/issues/67.

mcomer-captech, 2023-12-12:
@iMicknl unfortunately no luck yet with the info from #67. I do get +5v on Pin 1 and Gnd on Pin 2.

I threw together a sketch to send commands from an ESP32 I have around. I tried using both the "wake" as well as the "child lock" commands (since someone else said their controller seemed to respond to this command). I tried sending these both with and without "PIN20" pulled high. I used my 'scope to monitor several of the other pins for activity. Nothing I did caused the screen to light up or the controller to respond in any way, nothing on any of the other lines. I do see some slight voltage shifts and some motor controller noise on several of the other lines if I manually activate the controls.

This feels very much like the situation discussed in #25. I don't see that the gents there ever made any progress? It feels like there is something needed to activate this port. I may have to resort to following traces on the board and trying to figure out what goes where.

One other option - the manufacturer did very helpfully label  SDA and SCL on the little interconnect that goes between the main board and the display / button board - so maybe some kind of I2C man-in-the-middle? Probably very complicated to implement...

madninjaskillz, 2024-03-26:
I have one of these and have it somewhat working. The "universal" pinout doesn't work, i think i used the HS13B-1 wiring. It seems the serial data has changed slightly on this model:

* Up + Down work but the frequency of 108ms seems to be less than how long an up/down command executes for.
* Presets do not work
* pulsing memory will update height (which can often get out of sync)
* pulsing memory will turn on screen - but sometimes needs to be pulsed twice.
* Virtual Screen doesnt seem to do anything

because up and down operate for a while, stop is unreliable and setting a height via a number value is unusable (often overshoots)

While commands are being sent to the desk, the control panel on desk is unresponsive, and currently the only sure way to stop an UP is to send DOWN, things get jammed.

I'm currently very unscientifically trying stuff out via modifying the esp home yaml, might try and get the esp home to act as a serial converter so i can be a bit more methodical.

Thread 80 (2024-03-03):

ESP8266 D1 Mini not receiving output

philxws692, 2024-03-03:
Hey there,

I stumbled upon this great project and gave it a try.
I use a Wemos D1 Mini with the ESP8266 chipset as a controller, unfortunately I had to go through a little bit of trial and error because the desk I got, which is the Flexispot E6, with the HS17B-1 handset, was not confirmed to be working.
Nevertheless I somehow managed to get it sending commands to the desk and using my presets. However it does not receive any output from the controller, I already confirmed this by using the `ESP_LOGD` function from the `desk_height_sensor.h`.
For the RX Pin I tried using the RX Pin on the Wemos D1 Mini, and also tried using something like the D5, D6 Pins as described, but I can not get it to work.

Does anybody had similar experience, maybe also with the Flexispot E6?

Nama, 2025-01-15:
Should have looked for issues for this... I'm struggling with this issue since yesterday and I am out of ideas...

I'm using the ESP8266 NodeMCU dev board.

<details>

<summary>My code</summary>

```yml
ota:
  - platform: esphome
    password: "xxxxxxxx"

substitutions:
  min_height: "60" # cm
  max_height: "120" # cm
  c_screen_pin: D2
  c_tx_pin: D5
  c_rx_pin: D6
  k_screen_pin: D7
  k_tx_pin: D0
  k_rx_pin: D1
  friendly_name: "Mu Desk"
  name: "desk-1"

esphome:
  name: ${name}
  friendly_name: ${friendly_name}
  includes:
    - desk_height_sensor.h
    - desk_keypad.h
  on_boot:
    priority: -10
    then:
      - switch.turn_on: switch_wake_up

external_components:
  source: github://iMicknl/LoctekMotion_IoT
  components: [ loctekmotion_desk_height ]

logger:

esp8266:
  board: nodemcuv2

wifi:
  ssid: ""
  password: ""

  ap:
    ssid: "recover me ${friendly_name}"

captive_portal:

mqtt:
  broker: 192.168.1.3
  discover_ip: false
  discovery: false
  discovery_retain: false
  on_message:
    - topic: cmnd/desk/sit
      qos: 0
      then:
        - button.press: button_sit
    - topic: cmnd/desk/stand
      qos: 0
      then:
        - button.press: button_stand
    - topic: cmnd/desk/screen
      qos: 0
      then:
        - button.press: button_wake_screen

uart:
  - id: desk_uart
    baud_rate: 9600
    tx_pin: ${c_tx_pin}
    rx_pin: ${c_rx_pin}

  - id: keypad_uart
    baud_rate: 9600
    tx_pin: ${k_tx_pin}
    rx_pin: ${k_rx_pin}

script:
  - id: screen_timer
    mode: restart
    then:
     # on_start
     - logger.log: "Executing screen timer command"
     - switch.turn_on: virtual_screen
     - delay: 12s  # timer length (keypad screen timeout is 10s + 2s buffer)
     - if:
        condition:
         binary_sensor.is_off : screen
        then:
        - switch.turn_off: virtual_screen
     # on_end

  - id: script_start_command
    mode: restart
    then:
     - logger.log: "Executing Empty command"
     - if:
        condition:
         switch.is_off : virtual_screen
        then:
          - script.execute: screen_timer
          - delay: 480ms
        else:
          - script.execute: screen_timer

binary_sensor:
  - platform: gpio
    name: "Screen"
    id: "screen"
    pin: ${k_screen_pin}
    internal: false
    on_press:
      then:
        - switch.turn_on: virtual_screen
    on_release:
      then:
        - switch.turn_off: virtual_screen

sensor:
  - platform: wifi_signal
    name: "WiFi Signal"
    update_interval: 60s

  - platform: uptime
    name: Uptime

  - platform: loctekmotion_desk_height
    id: "desk_height"
    name: Desk Height
    uart_id: desk_uart
    filters:
    - clamp:
        min_value: ${min_height}
        max_value: ${max_height}
        ignore_out_of_range: true
    - debounce: 10ms
    on_value_range:
      - below: ${min_height}
        then:
          - switch.turn_off: switch_down
      - above: ${max_height}
        then:
          - switch.turn_off: switch_up
    on_value:
      then:
        - script.execute: screen_timer
        - component.update: set_desk_height

  - platform: custom
    lambda: |-
      auto desk_keypad_sensor = new DeskKeypad(id(keypad_uart));
      App.register_component(desk_keypad_sensor);
      return {desk_keypad_sensor};
    sensors:
      id: "desk_command"
      name: Desk command
      icon: "mdi:counter"
      on_value:
        then:
          lambda: |-
            if(id(desk_command).state == 1)
            {
              id(desk_cover).make_call().set_command_open().perform();
            } else if(id(desk_command).state == 2)
            {
              id(desk_cover).make_call().set_command_close().perform();
            } else if(id(desk_command).state == 3)
            {
              id(button_stand).press();
            } else if(id(desk_command).state == 4)
            {
              id(button_sit).press();
            } else if(id(desk_command).state == 5)
            {
              id(button_3).press();
            }  else if(id(desk_command).state == 6)
            {
              id(button_4).press();
            } else if(id(desk_command).state == 7)
            {
              id(button_m).press();
            } else if(id(desk_command).state == 8)
            {
              id(desk_cover).make_call().set_command_stop().perform();
            }

button:
  - platform: uart
    name: "Step Up"
    id: button_up
    icon: mdi:arrow-up-bold
    data: [0x9b, 0x06, 0x02, 0x01, 0x00, 0xfc, 0xa0, 0x9d]
    uart_id: desk_uart

  - platform: uart
    name: "Step Down"
    id: button_down
    icon: mdi:arrow-down-bold
    data: [0x9b, 0x06, 0x02, 0x02, 0x00, 0x0c, 0xa0, 0x9d]
    uart_id: desk_uart

  - platform: template
    name: "Stand"
    icon: mdi:numeric-1-box
    id: button_stand
    on_press:
      - uart.write:
          id: desk_uart
          data: [0x9b, 0x06, 0x02, 0x04, 0x00, 0xac, 0xa3, 0x9d]

  - platform: template
    name: "Sit"
    icon: mdi:numeric-2-box
    id: button_sit
    on_press:
      - uart.write:
          id: desk_uart
          data: [0x9b, 0x06, 0x02, 0x08, 0x00, 0xac, 0xa6, 0x9d]

  - platform: template
    name: "Preset 3"
    icon: mdi:chair-rolling
    id: button_3
    on_press:
      - uart.write:
          id: desk_uart
          data: [0x9b, 0x06, 0x02, 0x00, 0x01, 0xac, 0x60, 0x9d]

  - platform: template
    name: "Preset 4" # Preset 4 on some control panels
    icon: mdi:human-handsup
    id: button_4
    on_press:
      - uart.write:
          id: desk_uart
          data: [0x9b, 0x06, 0x02, 0x10, 0x00, 0xac, 0xac, 0x9d]

  - platform: template
    name: "Memory"
    id: button_m
    icon: mdi:alpha-m-box
    entity_category: "config"
    on_press:
      - uart.write:
          id: desk_uart
          data: [0x9b, 0x06, 0x02, 0x20, 0x00, 0xac, 0xb8, 0x9d]

  - platform: template
    name: "Wake Screen"
    id: button_wake_screen
    icon: mdi:gesture-tap-button
    entity_category: "config"
    on_press:
      - uart.write:
          id: desk_uart
          data: [0x9b, 0x06, 0x02, 0x00, 0x00, 0x6c, 0xa1, 0x9d]

switch:
  - platform: gpio
    name: "Virtual Screen"
    id: "virtual_screen"
    pin:
      number: ${c_screen_pin}
      mode: OUTPUT
    restore_mode: ALWAYS_ON
    internal: true

  - platform: uart
    name: "Up"
    id: switch_up
    icon: mdi:arrow-up-bold
    data: [0x9b, 0x06, 0x02, 0x01, 0x00, 0xfc, 0xa0, 0x9d]
    uart_id: desk_uart
    send_every: 1ms
    on_turn_on:
      then:
        - switch.turn_off: switch_down
    internal: true

  - platform: uart
    name: "Down"
    id: switch_down
    icon: mdi:arrow-down-bold
    data: [0x9b, 0x06, 0x02, 0x02, 0x00, 0x0c, 0xa0, 0x9d]
    uart_id: desk_uart
    send_every: 1ms
    on_turn_on:
      then:
        - switch.turn_off: switch_up
    internal: true

  - platform: uart
    name: "(wake up)" # Not available on all control panels
    id: switch_wake_up
    icon: mdi:gesture-tap-button
    data: [0x9b, 0x06, 0x02, 0x00, 0x00, 0x6c, 0xa1, 0x9d]
    uart_id: desk_uart
    internal: true

  - platform: uart
    name: "Empty command"
    id: switch_empty
    data: [0x9b, 0x06, 0x02, 0x00, 0x00, 0x6c, 0xa1, 0x9d]
    uart_id: desk_uart
    internal: false

cover:
  #- platform: template
  #  icon: mdi:table-chair
  #  # icon: mdi-human-male-height-variant
  #  name: "Desk"
  #  id: "desk"
  #  assumed_state: true
  #  has_position: true
  #  # set current position percent
  #  lambda: return (float(id(desk_height).state) - float(62.1)) / (float(126.9) - float(62.1));

  - platform: template
    id: desk_cover
    icon: mdi:table-chair
    name: "Desk"
    assumed_state: true
    optimistic: true

    # Move desk up
    open_action:
      - if:
          condition:
            - switch.is_on: switch_down
          then:
            - switch.turn_off: switch_down
            - delay: 500ms
      - switch.turn_on: switch_up

    # Move desk down
    close_action:
      - if:
          condition:
            - switch.is_on: switch_up
          then:
            - switch.turn_off: switch_up
            - delay: 500ms
      - switch.turn_on: switch_down

    stop_action:
      then:
        - switch.turn_off: switch_down
        - switch.turn_off: switch_up

number:
  - platform: template
    name: "Desk Height"
    id: set_desk_height
    min_value: ${min_height}
    max_value: ${max_height}
    icon: "mdi:counter"
    unit_of_measurement: "cm"
    device_class: "distance"
    step: 0.1
    lambda: !lambda |-
      return id(desk_height).state;
    set_action:
      - if:
          condition:
            - lambda: !lambda |-
                return x > id(desk_height).state;
          then:
            # direction up
            - cover.open: desk_cover
            - wait_until:
                lambda: |-
                  return id(desk_height).state  >= x - 1;
            - cover.stop: desk_cover
            - delay: 1s
            # move a little down again to adjust for momentum
            - uart.write:
                id: desk_uart
                data: [0x9b, 0x06, 0x02, 0x02, 0x00, 0x0c, 0xa0, 0x9d] # down
          else:
            # direction down
            - cover.close: desk_cover
            - wait_until:
                lambda: |-
                  return id(desk_height).state <= x + 3;
            - cover.stop: desk_cover
            - delay: 1s
            # move a little up again to adjust for momentum
            - uart.write:
                id: desk_uart
                data: [0x9b, 0x06, 0x02, 0x01, 0x00, 0xfc, 0xa0, 0x9d] # up
```
</details>

Nama, 2025-01-17:
I disconnected TX and bridged RX to the controller and everything works now.

So reading from keypad is not necessary.

Makr91, 2025-03-02:
> I disconnected TX and bridged RX to the controller and everything works now.
>
> So reading from keypad is not necessary.

Now that ESPhome has deprecated custom components, do you by chance have an updated version of this?

Nama, 2025-03-02:
No, I didn't update.

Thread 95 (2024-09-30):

Desk Height

wernerhp, 2024-09-30:
The desk height component has some glitches.

When setting the height from 72.5cm to 105cm it starts but then stops shortly after with with a height value of 800cm (I suspect this hsould be 80.0cm).
Similarly, when it lowers from 105cm to 72.5, it stops shortly after with a height value of 10cm (I suspect this should be 100.0cm)

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

https://github.com/user-attachments/assets/eba648d9-71a5-4aa3-b842-8471fe5c6cf0

iMicknl, 2024-10-18:
Which version do you use? We just published a new version of this component, see the README.

Number entity will still overshoot, but in general the code is better.

wernerhp, 2024-10-18:
I tried `main` and `v2`

```
source: github://iMicknl/LoctekMotion_IoT@v2
  components: [ loctekmotion_desk_height ]
```

wernerhp, 2024-10-18:
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

I'd have expected the cponent to be updated. That's where the problem appeared to have been

iMicknl, 2024-10-18:
@wernerhp I would need to investigate if I face the same issue, or if your device is different..

wernerhp, 2024-10-22:
Have a look at this height decoder
https://www.mikrocontroller.net/attachment/452474/Schreibtisch_Dekoder.xlsx

Maybe you could add a test to check that the examples form the sheet are correctly decoded.

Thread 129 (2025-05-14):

Help: Identify Board RF387A V1.5 - No RX

The-May, 2025-05-14:
Hi Guys,

I managed to reduce height + stop manually + use presets via esphome but for some reason I dont get any height report and increasing height does also not work.
The Docs dont really help becasue i cannot find any hint if it is a HS13B-1, HS13A-1,  HS01B-1,  etc.

**Wiring:**

I tried to stick to the OG Docs and wired everything on my ESP32 D1 Mini Clone:

I am using a usb-cable that is connected to the Port of the ESP32 that draws the 5v + GND from my Desk. (PIN 8 + 7), so I seem to have identified +5 and GND,
Ans also since I can drive down my desk i would say my guess on TX is also right but RX seems to be not right...

My Board (yellow highlighted are used GPIO pins):

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

I am Struggling to identify my PCB/Board and to identify what the issue is.
I could not find any fitting model description, therefore I just did pictures of everything...

this is my Panel:

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

PCB Front:

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

PCB Back:

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

PSU:

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

Cable Colors:

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

Desk:
name:E.For.U® DT30

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

If someone could help me, this would be awesome.....
Thanks in advance

**Code:**
I sticked to the [original yaml](https://github.com/iMicknl/LoctekMotion_IoT/blob/main/packages/office-desk-esp32.yaml), since the substitutions are easy and not messy like the other examples from the others.

 ````` substitutions:
  device_name: esp8266-smartdesk-0c3544
  name: esp8266-smartdesk-0c3544
  min_height: "65.5" # cm
  max_height: "129" # cm
  ssid: !secret wifi_ssid
  wifi_password: !secret wifi_password
  ap_fallback_password: !secret fallback_pass
  tx_pin: GPIO17 # TXD 2
  rx_pin: GPIO16 # RXD 2
  screen_pin: GPIO23
  encryption_key: !secret api_encryption_key

external_components:
  source: github://iMicknl/LoctekMotion_IoT
  components: [ loctekmotion_desk_height ]

esp32:
  board: esp32dev
  framework:
    type: arduino

esphome:
  name: ${name}
  friendly_name: ${device_name}
  comment: Used to control your ${device_name} standing desk via Home Assistant.

  # Wake Desk by sending the "M" command
  # This will pull the current height after boot
  on_boot:
    priority: -10
    then:
      - button.press: button_m

# Enable logging
logger:

# Enable Home Assistant API
api:
  encryption:
    key: ${encryption_key}

ota:
  platform: esphome

wifi:
  ssid: ${ssid}
  password: ${wifi_password}

  # Enable fallback hotspot (captive portal) in case wifi connection fails
  ap:
    ssid: ${device_name}
    password: ${ap_fallback_password}

captive_portal:

uart:
  - id: desk_uart
    baud_rate: 9600
    tx_pin: ${tx_pin}
    rx_pin: ${rx_pin}
    # debug:

sensor:
  - platform: wifi_signal
    name: "WiFi Signal"
    update_interval: 60s

  - platform: uptime
    name: Uptime

  - platform: loctekmotion_desk_height
    id: "desk_height"
    name: Desk Height
    on_value_range:
    - below: ${min_height}
      then:
        - switch.turn_off: switch_down
    - above: ${max_height}
      then:
        - switch.turn_off: switch_up
    on_value:
      then:
        - cover.template.publish:
            id: desk_cover
            position: !lambda |-
                // The sensor outputs values from min_height (cm) to max_height (cm)
                // We need to translate this to 0 - 1 scale.
                float position = (float(x) - float(${min_height})) / (float(${max_height}) - float(${min_height}));
                return position;
        - component.update: set_desk_height

switch:
  - platform: gpio
    name: "Virtual Screen" # PIN20
    pin:
      number: ${screen_pin}
      mode: OUTPUT
    restore_mode: ALWAYS_ON
    entity_category: "config"
    internal: true

  - platform: uart
    name: "Up"
    id: switch_up
    icon: mdi:arrow-up-bold
    data: [0x9b, 0x06, 0x02, 0x01, 0x00, 0xfc, 0xa0, 0x9d]
    uart_id: desk_uart
    send_every: 108ms
    internal: true

  - platform: uart
    name: "Down"
    id: switch_down
    icon: mdi:arrow-down-bold
    data: [0x9b, 0x06, 0x02, 0x02, 0x00, 0x0c, 0xa0, 0x9d]
    uart_id: desk_uart
    send_every: 108ms
    internal: true

  - platform: uart
    name: "Alarm off"
    id: switch_alarm
    icon: mdi:alarm
    data: [0x9b, 0x06, 0x02, 0x40, 0x00, 0xAC, 0x90, 0x9d]
    uart_id: desk_uart
    send_every: 108ms
    on_turn_on:
      - delay: 3000ms
      - switch.turn_off: switch_alarm
    entity_category: "config"

  - platform: uart
    name: "Child Lock"
    id: switch_child_lock
    icon: mdi:account-lock
    data: [0x9b, 0x06, 0x02, 0x20, 0x00, 0xac, 0xb8, 0x9d]
    uart_id: desk_uart
    send_every: 108ms
    on_turn_on:
      - delay: 5000ms
      - switch.turn_off: switch_child_lock
    entity_category: "config"

button:
  - platform: template
    name: "Preset 1"
    icon: mdi:numeric-1-box
    on_press:
      - uart.write:
          id: desk_uart
          data: [0x9b, 0x06, 0x02, 0x04, 0x00, 0xac, 0xa3, 0x9d]

  - platform: template
    name: "Preset 2"
    icon: mdi:numeric-2-box
    on_press:
      - uart.write:
          id: desk_uart
          data: [0x9b, 0x06, 0x02, 0x08, 0x00, 0xac, 0xa6, 0x9d]

  - platform: template
    name: "Sit" # Preset 3 on some control panels
    icon: mdi:chair-rolling
    on_press:
      - uart.write:
          id: desk_uart
          data: [0x9b, 0x06, 0x02, 0x00, 0x01, 0xac, 0x60, 0x9d]

  - platform: template
    name: "Stand" # Preset 4 on some control panels
    icon: mdi:human-handsup
    on_press:
      - uart.write:
          id: desk_uart
          data: [0x9b, 0x06, 0x02, 0x10, 0x00, 0xac, 0xac, 0x9d]

  - platform: template
    name: "Memory"
    id: button_m
    icon: mdi:alpha-m-box
    entity_category: "config"
    on_press:
      - uart.write:
          id: desk_uart
          data: [0x9b, 0x06, 0x02, 0x20, 0x00, 0xac, 0xb8, 0x9d]

  - platform: template
    name: "Wake Screen"
    id: button_wake_screen
    icon: mdi:gesture-tap-button
    entity_category: "config"
    on_press:
      - uart.write:
          id: desk_uart
          data: [0x9b, 0x06, 0x02, 0x00, 0x00, 0x6c, 0xa1, 0x9d]

  - platform: template
    name: "Alarm"
    id: button_alarm
    icon: mdi:alarm
    on_press:
      - uart.write:
          id: desk_uart
          data: [0x9b, 0x06, 0x02, 0x40, 0x00, 0xAC, 0x90, 0x9d]

  - platform: restart
    name: "Restart"
    entity_category: "config"

cover:
  - platform: template
    id: "desk_cover"
    icon: mdi:desk # or mdi:human-male-height-variant
    name: "Desk"
    device_class: blind # makes it easier to integrate with Google/Alexa
    has_position: true
    position_action:
      - if:
          condition:
            - lambda: !lambda |-
                return pos > id(desk_cover).position;
          then:
            - cover.open: desk_cover
            - wait_until:
                lambda: |-
                  return id(desk_cover).position  >= pos;
            - cover.stop: desk_cover
          else:
            - cover.close: desk_cover
            - wait_until:
                lambda: |-
                  return id(desk_cover).position <= pos;
            - cover.stop: desk_cover
    stop_action:
      - switch.turn_off: switch_up
      - switch.turn_off: switch_down
    open_action:
      - switch.turn_off: switch_down
      - switch.turn_on: switch_up
    close_action:
      - switch.turn_off: switch_up
      - switch.turn_on: switch_down
    optimistic: false

number:
  - platform: template
    name: "Desk Height"
    id: set_desk_height
    min_value: ${min_height}
    max_value: ${max_height}
    icon: "mdi:counter"
    unit_of_measurement: "cm"
    device_class: "distance"
    step: 0.1
    lambda: !lambda |-
      return id(desk_height).state;
    set_action:
      - if:
          condition:
            - lambda: !lambda |-
                return x > id(desk_height).state;
          then:
            - cover.open: desk_cover
            - wait_until:
                lambda: |-
                  return id(desk_height).state  >= x;
            - cover.stop: desk_cover
          else:
            - cover.close: desk_cover
            - wait_until:
                lambda: |-
                  return id(desk_height).state <= x;
            - cover.stop: desk_cover `````

The-May, 2025-05-14:
Okay I think I found the issue: It was a dead wire on RX-Side.
Used a multimeter and could find out that the cable went to hell.
Now since I rewired and reused another cable, everything works out of the box.
Hope this helps someone.....

Closed 2025-05-14.

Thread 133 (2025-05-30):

[not working] Flexispot E1 with HCB223A-1

nedhimself, 2025-05-30:
I was able to upload the code to a esp32 devkitv1.
In home assistant I can read the desk height but I cannot send any command to the desk.
Here is the code that I'm using.

```
substitutions:
  device_name: Flexispot EK5
  name: office-desk-flexispot-ek5
  min_height: "71" # cm
  max_height: "121" # cm
  tx_pin: GPIO17 # TXD 2
  rx_pin: GPIO16 # RXD 2
  screen_pin: GPIO23

external_components:
  source: github://iMicknl/LoctekMotion_IoT
  components: [ loctekmotion_desk_height ]

esp32:
  board: esp32dev
  framework:
    type: arduino

esphome:
  name: ${name}
  friendly_name: ${device_name}
  comment: Used to control your ${device_name} standing desk via Home Assistant.

  # Wake Desk by sending the "M" command
  # This will pull the current height after boot
  on_boot:
    priority: -10
    then:
      - button.press: button_m

# Enable logging
logger:

# Enable Home Assistant API
api:
  encryption:
    key: ...

ota:
  - platform: esphome
    password: ...

wifi:
  ssid: !secret wifi_ssid
  password: !secret wifi_password

  # Enable fallback hotspot (captive portal) in case wifi connection fails
  ap:
    ssid: "Test Fallback Hotspot"
    password: ...

captive_portal:

uart:
  - id: desk_uart
    baud_rate: 9600
    tx_pin: ${tx_pin}
    rx_pin: ${rx_pin}
    # debug:

sensor:
  - platform: wifi_signal
    name: "WiFi Signal"
    update_interval: 60s

  - platform: uptime
    name: Uptime

  - platform: loctekmotion_desk_height
    id: "desk_height"
    name: Desk Height
    on_value_range:
    - below: ${min_height}
      then:
        - switch.turn_off: switch_down
    - above: ${max_height}
      then:
        - switch.turn_off: switch_up
    on_value:
      then:
        - cover.template.publish:
            id: desk_cover
            position: !lambda |-
                // The sensor outputs values from min_height (cm) to max_height (cm)
                // We need to translate this to 0 - 1 scale.
                float position = (float(x) - float(${min_height})) / (float(${max_height}) - float(${min_height}));
                return position;
        - component.update: set_desk_height

switch:
  - platform: gpio
    name: "Virtual Screen" # PIN20
    pin:
      number: ${screen_pin}
      mode: OUTPUT
    restore_mode: ALWAYS_ON
    entity_category: "config"
    internal: true

  - platform: uart
    name: "Up"
    id: switch_up
    icon: mdi:arrow-up-bold
    data: [0x9b, 0x06, 0x02, 0x01, 0x00, 0xfc, 0xa0, 0x9d]
    uart_id: desk_uart
    send_every: 108ms
    internal: true

  - platform: uart
    name: "Down"
    id: switch_down
    icon: mdi:arrow-down-bold
    data: [0x9b, 0x06, 0x02, 0x02, 0x00, 0x0c, 0xa0, 0x9d]
    uart_id: desk_uart
    send_every: 108ms
    internal: true

  - platform: uart
    name: "Alarm off"
    id: switch_alarm
    icon: mdi:alarm
    data: [0x9b, 0x06, 0x02, 0x40, 0x00, 0xAC, 0x90, 0x9d]
    uart_id: desk_uart
    send_every: 108ms
    on_turn_on:
      - delay: 3000ms
      - switch.turn_off: switch_alarm
    entity_category: "config"

  - platform: uart
    name: "Child Lock"
    id: switch_child_lock
    icon: mdi:account-lock
    data: [0x9b, 0x06, 0x02, 0x20, 0x00, 0xac, 0xb8, 0x9d]
    uart_id: desk_uart
    send_every: 108ms
    on_turn_on:
      - delay: 5000ms
      - switch.turn_off: switch_child_lock
    entity_category: "config"

button:
  - platform: template
    name: "Preset 1"
    icon: mdi:numeric-1-box
    on_press:
      - uart.write:
          id: desk_uart
          data: [0x9b, 0x06, 0x02, 0x04, 0x00, 0xac, 0xa3, 0x9d]

  - platform: template
    name: "Preset 2"
    icon: mdi:numeric-2-box
    on_press:
      - uart.write:
          id: desk_uart
          data: [0x9b, 0x06, 0x02, 0x08, 0x00, 0xac, 0xa6, 0x9d]

  - platform: template
    name: "Sit" # Preset 3 on some control panels
    icon: mdi:chair-rolling
    on_press:
      - uart.write:
          id: desk_uart
          data: [0x9b, 0x06, 0x02, 0x00, 0x01, 0xac, 0x60, 0x9d]

  - platform: template
    name: "Stand" # Preset 4 on some control panels
    icon: mdi:human-handsup
    on_press:
      - uart.write:
          id: desk_uart
          data: [0x9b, 0x06, 0x02, 0x10, 0x00, 0xac, 0xac, 0x9d]

  - platform: template
    name: "Memory"
    id: button_m
    icon: mdi:alpha-m-box
    entity_category: "config"
    on_press:
      - uart.write:
          id: desk_uart
          data: [0x9b, 0x06, 0x02, 0x20, 0x00, 0xac, 0xb8, 0x9d]

  - platform: template
    name: "Wake Screen"
    id: button_wake_screen
    icon: mdi:gesture-tap-button
    entity_category: "config"
    on_press:
      - uart.write:
          id: desk_uart
          data: [0x9b, 0x06, 0x02, 0x00, 0x00, 0x6c, 0xa1, 0x9d]

  - platform: template
    name: "Alarm"
    id: button_alarm
    icon: mdi:alarm
    on_press:
      - uart.write:
          id: desk_uart
          data: [0x9b, 0x06, 0x02, 0x40, 0x00, 0xAC, 0x90, 0x9d]

  - platform: restart
    name: "Restart"
    entity_category: "config"

cover:
  - platform: template
    id: "desk_cover"
    icon: mdi:desk # or mdi:human-male-height-variant
    name: "Desk"
    device_class: blind # makes it easier to integrate with Google/Alexa
    has_position: true
    position_action:
      - if:
          condition:
            - lambda: !lambda |-
                return pos > id(desk_cover).position;
          then:
            - cover.open: desk_cover
            - wait_until:
                lambda: |-
                  return id(desk_cover).position  >= pos;
            - cover.stop: desk_cover
          else:
            - cover.close: desk_cover
            - wait_until:
                lambda: |-
                  return id(desk_cover).position <= pos;
            - cover.stop: desk_cover
    stop_action:
      - switch.turn_off: switch_up
      - switch.turn_off: switch_down
    open_action:
      - switch.turn_off: switch_down
      - switch.turn_on: switch_up
    close_action:
      - switch.turn_off: switch_up
      - switch.turn_on: switch_down
    optimistic: false

number:
  - platform: template
    name: "Desk Height"
    id: set_desk_height
    min_value: ${min_height}
    max_value: ${max_height}
    icon: "mdi:counter"
    unit_of_measurement: "cm"
    device_class: "distance"
    step: 0.1
    lambda: !lambda |-
      return id(desk_height).state;
    set_action:
      - if:
          condition:
            - lambda: !lambda |-
                return x > id(desk_height).state;
          then:
            - cover.open: desk_cover
            - wait_until:
                lambda: |-
                  return id(desk_height).state  >= x;
            - cover.stop: desk_cover
          else:
            - cover.close: desk_cover
            - wait_until:
                lambda: |-
                  return id(desk_height).state <= x;
            - cover.stop: desk_cover
```

iMicknl, 2025-06-16:
@nedhimself what was the fix? (for other people stumbling on your issue)

Closed 2025-06-09.

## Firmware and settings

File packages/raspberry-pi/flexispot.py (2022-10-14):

import serial
import RPi.GPIO as GPIO
import sys

SERIAL_PORT = "/dev/ttyS0" # GPIO14 (TX) and GPIO15 (RX)
PIN_20 = 12 # GPIO 12

SUPPORTED_COMMANDS = {
    "up": bytearray(b'\x9b\x06\x02\x01\x00\xfc\xa0\x9d'),
    "down": bytearray(b'\x9b\x06\x02\x02\x00\x0c\xa0\x9d'),
    "m": bytearray(b'\x9b\x06\x02\x20\x00\xac\xb8\x9d'),
    "wake_up": bytearray(b'\x9b\x06\x02\x00\x00\x6c\xa1\x9d'),
    "preset_1": bytearray(b'\x9b\x06\x02\x04\x00\xac\xa3\x9d'),
    "preset_2": bytearray(b'\x9b\x06\x02\x08\x00\xac\xa6\x9d'),
    "preset_3": bytearray(b'\x9b\x06\x02\x10\x00\xac\xac\x9d'),
    "preset_4": bytearray(b'\x9b\x06\x02\x00\x01\xac\x60\x9d'),
}

class LoctekMotion():

    def __init__(self, serial, pin_20):
        """Initialize LoctekMotion"""
        self.serial = serial

        # Or GPIO.BOARD - GPIO Numbering vs Pin numbering
        GPIO.setmode(GPIO.BCM)

        # Turn desk in operating mode by setting controller pin20 to HIGH
        # This will allow us to send commands and to receive the current height
        GPIO.setup(pin_20, GPIO.OUT)
        GPIO.output(pin_20, GPIO.HIGH)

    def execute_command(self, command_name: str):
        """Execute command"""
        command = SUPPORTED_COMMANDS.get(command_name)

        if not command:
            raise Exception("Command not found")

        self.serial.write(command)

    def decode_seven_segment(self, byte):
        binaryByte = bin(byte).replace("0b","").zfill(8)
        decimal = False
        if binaryByte[0] == "1":
            decimal = True
        if binaryByte[1:] == "0111111":
            return 0, decimal
        if binaryByte[1:] == "0000110":
            return 1, decimal
        if binaryByte[1:] == "1011011":
            return 2, decimal
        if binaryByte[1:] == "1001111":
            return 3, decimal
        if binaryByte[1:] == "1100110":
            return 4, decimal
        if binaryByte[1:] == "1101101":
            return 5, decimal
        if binaryByte[1:] == "1111101":
            return 6, decimal
        if binaryByte[1:] == "0000111":
            return 7, decimal
        if binaryByte[1:] == "1111111":
            return 8, decimal
        if binaryByte[1:] == "1101111":
            return 9, decimal
        if binaryByte[1:] == "1000000":
            return 10, decimal
        return -1, decimal

    def current_height(self):
        history = [None] * 5
        msg_type = 0
        msg_len = 0
        valid = False
        while True:
            try:
                # read in each byte
                data = self.serial.read(1)
                # 9b starts the data
                # the value after 9b has the length of the packet
                if history[0] == 0x9b:
                    msg_len = data[0]
                if history[1] == 0x9b:
                    msg_type = data[0]
                if history[2] == 0x9b:
                    if msg_type == 0x12 and msg_len == 7:
                        if data[0] == 0:
                            print("height is empty                ", end='\r')
                        else:
                            valid = True
                if history[3] == 0x9b:
                    if valid == True:
                         pass
                if history[4] == 0x9b:
                    if valid == True and msg_len == 7:
                        height1, decimal1 = self.decode_seven_segment(history[1])
                        height1 = height1 * 100
                        height2, decimal2 = self.decode_seven_segment(history[0])
                        height2 = height2 * 10
                        height3, decimal3 = self.decode_seven_segment(data[0])
                        if height1 < 0 or height2 < 0 or height3 < 0:
                            print("Display Empty","          ",end='\r')
                        else:
                            finalHeight = height1 + height2 + height3
                            decimal = decimal1 or decimal2 or decimal3
                            if decimal == True:
                                finalHeight = finalHeight/10
                            print("Height:",finalHeight,"       ",end='\r')
                history[4] = history[3]
                history[3] = history[2]
                history[2] = history[1]
                history[1] = history[0]
                history[0] = data[0]
            except Exception as e:
                print(e)
                break

def main():
    try:
        command = sys.argv[1]
        ser = serial.Serial(SERIAL_PORT, 9600, timeout=500)
        locktek = LoctekMotion(ser, PIN_20)
        locktek.execute_command(command)
        locktek.current_height()
    # Error handling for serial port
    except serial.SerialException as e:
        print(e)
        return
    # Error handling for command line arguments
    except IndexError:
        program = sys.argv[0]
        print("Usage: python3",program,"[COMMAND]")
        print("Supported Commands:")
        for command in SUPPORTED_COMMANDS:
            print("\t", command)
        sys.exit(1)
    except KeyboardInterrupt:
        sys.exit(1)
    finally:
        GPIO.cleanup()

if __name__ == "__main__":
    main()

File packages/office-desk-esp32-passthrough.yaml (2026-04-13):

substitutions:
  device_name: Flexispot desk
  name: office-desk-flexispot
  unit_of_measurement: "cm" # or "in"
  min_height: "73.5"
  max_height: "123"
  ssid: !secret wifi_ssid
  wifi_password: !secret wifi_password
  ap_fallback_password: !secret ap_fallback_password
  tx_pin: GPIO17 # TXD 2
  rx_pin: GPIO16 # RXD 2
  rx_pin_keypad: GPIO3 # RX 0
  screen_pin: GPIO23
  encryption_key: !secret encryption_key

external_components:
  source: github://iMicknl/LoctekMotion_IoT
  components: [loctekmotion_desk_height, loctekmotion_desk_command]

esp32:
  board: esp32dev
  framework:
    type: arduino

esphome:
  name: ${name}
  friendly_name: ${device_name}
  comment: Used to control your ${device_name} standing desk via Home Assistant.

  # Delay UART interaction on boot to give the desk controller time to initialize.
  # After the delay, wake the desk by sending the "M" command to request the current height.
  on_boot:
    priority: -100
    then:
      - delay: 10s
      - button.press: button_wake_screen
      - delay: 300ms
      - button.press: button_m

# Enable logging
logger:

# Enable Home Assistant API
api:
  encryption:
    key: ${encryption_key}

ota:
  platform: esphome

wifi:
  ssid: ${ssid}
  password: ${wifi_password}

  # Enable fallback hotspot (captive portal) in case wifi connection fails
  ap:
    ssid: ${device_name} Fallback Hotspot
    password: ${ap_fallback_password}

captive_portal:

uart:
  - id: desk_uart
    baud_rate: 9600
    tx_pin: ${tx_pin}
    rx_pin: ${rx_pin}
    # debug:

  - id: keypad_uart
    baud_rate: 9600
    rx_pin: ${rx_pin_keypad}

sensor:
  - platform: wifi_signal
    name: "WiFi signal"
    update_interval: 60s

  - platform: uptime
    name: Uptime

  - platform: loctekmotion_desk_height
    id: "desk_height"
    name: Desk height
    unit_of_measurement: ${unit_of_measurement}
    uart_id: desk_uart
    on_value_range:
    - below: ${min_height}
      then:
        - switch.turn_off: switch_down
        - button.press: button_wake_screen
    - above: ${max_height}
      then:
        - switch.turn_off: switch_up
        - button.press: button_wake_screen
    on_value:
      then:
        - cover.template.publish:
            id: desk_cover
            position: !lambda |-
                // The sensor outputs values from min_height (cm) to max_height (cm)
                // We need to translate this to 0 - 1 scale.
                float position = (float(x) - float(${min_height})) / (float(${max_height}) - float(${min_height}));
                return position;
        - component.update: set_desk_height

  - platform: loctekmotion_desk_command
    id: "desk_command"
    name: Desk command
    uart_id: keypad_uart
    on_value_range: # The sensor outputs values 1 to 8 depending on the button pressed.
      - above: 1
        below: 1
        then:
          - switch.turn_on: switch_up
      - above: 2
        below: 2
        then:
          - switch.turn_on: switch_down
      - above: 3
        below: 3
        then:
          - button.press: button_preset1
      - above: 4
        below: 4
        then:
          - button.press: button_preset2
      - above: 5
        below: 5
        then:
          - button.press: button_stand
      - above: 6
        below: 6
        then:
          - button.press: button_m
      - above: 7
        below: 7
        then:
          - button.press: button_alarm
      - above: 8
        below: 8
        then: # When a button is released value 8 is sent, switches which send recurring data must be stopped.
          - switch.turn_off: switch_up
          - switch.turn_off: switch_down
          - button.press: button_wake_screen
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

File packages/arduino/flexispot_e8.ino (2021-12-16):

// developed by foxytocin
// website https://anfuchs.de
// based on code from iMicknl

#include <SoftwareSerial.h>

#define displayPin20 4 // D2 GPIO4
#define rxPin 12 // D5 GPIO12
#define txPin 14 // D6 GPIO14 

SoftwareSerial sSerial(rxPin, txPin); // RX, TX
byte history[2];

// Supported Commands
const byte wakeup[] = { 0x9b, 0x06, 0x02, 0x00, 0x00, 0x6c, 0xa1, 0x9d };
const byte command_up[] = { 0x9b, 0x06, 0x02, 0x01, 0x00, 0xfc, 0xa0, 0x9d };
const byte command_down[] = { 0x9b, 0x06, 0x02, 0x02, 0x00, 0x0c, 0xa0, 0x9d };
const byte command_m[] =  {0x9b, 0x06, 0x02, 0x20, 0x00, 0xac, 0xb8, 0x9d };
const byte command_preset_1[] = { 0x9b, 0x06, 0x02, 0x04, 0x00, 0xac, 0xa3, 0x9d };
const byte command_preset_2[] = { 0x9b, 0x06, 0x02, 0x08, 0x00, 0xac, 0xa6, 0x9d };
const byte command_preset_3[] = { 0x9b, 0x06, 0x02, 0x10, 0x00, 0xac, 0xac, 0x9d };
const byte command_preset_4[] = { 0x9b, 0x06, 0x02, 0x00, 0x01, 0xac, 0x60, 0x9d };


void setup() {
  Serial.begin(115200);   // Debug serial
  sSerial.begin(9600);    // Flexispot E8

  pinMode(displayPin20, OUTPUT);
  digitalWrite(displayPin20, LOW);

  // Executes a demo
  demo();
}


void demo() {

  // Calls sit-preset and waits 20 seconds
  sit();
  delay(20000);

  // Calls stand-preset and waits 20 seconds
  stand();
  delay(20000);

  // Wakeup the table to retrieve the current height
  // At the moment this is only represented as HEX value
  wake();
}


void turnon() {
  // Turn desk in operating mode by setting controller pin20 to HIGH
  Serial.println("sending turn on command");
  digitalWrite(displayPin20, HIGH);
  delay(1000);
  digitalWrite(displayPin20, LOW);
}


void wake() {
  turnon();

  // This will allow us to receive the current height
  Serial.println("sending wakeup command");
  sSerial.flush();
  sSerial.enableTx(true);
  sSerial.write(wakeup, sizeof(wakeup));
  sSerial.enableTx(false);
}


void sit() {
  turnon();

  // This send the preset_4 command to trigger the sit position
  Serial.println("sending sit preset (preset_4)");
  sSerial.flush();
  sSerial.enableTx(true);
  sSerial.write(command_preset_4, sizeof(command_preset_4));
  sSerial.enableTx(false);
}


void stand() {
  turnon();

  // This send the preset_3 command to trigger the stand position
  Serial.println("sending stand preset (preset_3)");
  sSerial.flush();
  sSerial.enableTx(true);
  sSerial.write(command_preset_3, sizeof(command_preset_3));
  sSerial.enableTx(false);
}


void loop() {
  while (sSerial.available())
  {
    unsigned long in = sSerial.read();

    // Start of packet
    if (in == 0x9b) {
      Serial.println();
    }

    // Second byte defines the message length
    if (history[0] == 0x9b) {
      int msg_len = (int)in;
      Serial.print("(LENGTH:");
      Serial.print(in);
      Serial.print(")");
    }

    // Get package length (second byte)
    history[1] = history[0];
    history[0] = in;

    // Print hex for debug
    Serial.print(in, HEX);
    Serial.print(" ");
  }
}

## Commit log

2021-03-07 Update Raspberry Pi documentation
2021-03-25 Add. desk height sensor (esphome)
2021-08-10 Add support for esp32 and control
2021-12-19 Fixed 'S-*' display readings (memory button)
    [desk_height_sensor.h]
2022-01-31 Add Ethernet cable color (T568B) to ESPHome Readme for better overview
2022-03-07 Update desk_height_sensor.h
    float value = NULL; -> float value = 0;
    ESPHome was marking this as a error, so I changed it in my code, still working.
    [desk_height_sensor.h]
2022-10-10 Error handling when no such serial port
    Fixes the "UnboundLocalError: local variable 'serial' referenced before assignment" error when the serial port does not exist.
    [flexispot.py]
2022-10-11 Implement current_height
    implemented current height as a constant on screen display, must use ctrl+c to exit
2023-07-25 fix address of height
    Some newer controllers (such as CB38M4A(IB)-1 (flexispot e7q) report their heigt with a msg_lenght of 10 instead of 7. This should be reverse-compatible, even though i have not tested that.
    [desk_height_sensor.h]
2024-05-23 First try at height sensor component
2024-07-14 Fix/clarify pin-out
2024-12-25 set `platform: esphome` in ota
    otherwise the following error occurs using ESPHome 2024.12.2:
    ```
    At least one platform must be specified for 'ota'; add 'platform: esphome' for original OTA functionality
    ```
    [office-desk-esp32.yaml]
2025-02-21 Fix case
2025-03-17 Description, images and link to 3D printed enclosure added
2025-10-05 wake screen before triggering action. fixes #114
    [office-desk-esp32.yaml]
2025-10-09 Update office-desk-esp32.yaml - send empty command to stop desk
    Potentially a solution to overshoot issue. Needs testing on more desks
    [office-desk-esp32.yaml]
2025-10-12 Add external component for pass through sensor
2025-10-12 Formatting of desk command sensor
2025-10-12 Clarification of desk command sensor in yaml
2025-10-12 Formatting of desk command sensor cpp
2026-01-04 Improve boot sequence for desk controllers by adding delays before UART command (#154)
    This pull request updates the boot sequence for several ESPHome desk
    controller configurations to ensure reliable initialization. The key
    change is introducing a delay before sending commands to the desk
    controller, allowing time for the hardware to power up and be ready for
    communication.
    This is especially helpful when the ESP is powered via the desk and the
    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
2026-01-12 Bump esphome from 2025.12.4 to 2025.12.5 (#165)
    Bumps [esphome](https://github.com/esphome/esphome) from 2025.12.4 to
    2025.12.5.
    <details>
    <summary>Release notes</summary>
    <p><em>Sourced from <a
    href="https://github.com/esphome/esphome/releases">esphome's
    releases</a>.</em></p>
    <blockquote>
    <h2>2025.12.5</h2>
    <ul>
    <li>[lvgl] Fix arc background angles <a
    href="https://redirect.github.com/esphome/esphome/pull/12773">esphome#12773</a>
    by <a
    href="https://github.com/clydebarrow"><code>@ clydebarrow</code></a></li>
    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
2026-03-02 Bump ruff from 0.15.2 to 0.15.4 (#184)
    [//]: # (dependabot-start)
    ⚠️ **Dependabot is rebasing this PR** ⚠️
    Rebasing might not happen immediately, so don't worry if this takes some
    time.
    Note: if you make any changes to this PR yourself, they will take
    precedence over the rebase.
    ---
    [//]: # (dependabot-end)
    Bumps [ruff](https://github.com/astral-sh/ruff) from 0.15.2 to 0.15.4.
    href="https://github.com/astral-sh/ruff/releases">ruff's
    <h2>0.15.4</h2>
    <h2>Release Notes</h2>
    <p>Released on 2026-02-26.</p>
    <p>This is a follow-up release to 0.15.3 that resolves a panic when the
    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
2026-03-09 Bump esphome from 2026.2.2 to 2026.2.4 (#186)
    Bumps [esphome](https://github.com/esphome/esphome) from 2026.2.2 to
    2026.2.4.
    <h2>2026.2.4</h2>
    <p>No release notes provided.</p>
    <h2>2026.2.3</h2>
    <li>[mqtt] Remove broken ESP8266 ssl_fingerprints option <a
    href="https://redirect.github.com/esphome/esphome/pull/14182">esphome#14182</a>
    by <a href="https://github.com/bdraco"><code>@ bdraco</code></a>
    (breaking-change)</li>
    <li>[sprinkler] Fix millis overflow and underflow bugs <a
    href="https://redirect.github.com/esphome/esphome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
2026-04-13 Improve configuration for desk that use "inch" (#180)
    - Add unit selection as a substitution option to easily switch between
    inches and centimeters
    - Remove the `ap_fallback_password` and `encryption_key` values
    - Add unit of measurement to the height sensor
2026-04-20 Bump esphome from 2026.3.3 to 2026.4.1 (#199)
    Bumps [esphome](https://github.com/esphome/esphome) from 2026.3.3 to
    2026.4.1.
    <h2>2026.4.1</h2>
    <li>[core] Fix app_state_ status bits clobbered for non-looping
    components <a
    href="https://redirect.git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
2026-05-18 Bump esphome from 2026.4.2 to 2026.4.5 (#205)
    Bumps [esphome](https://github.com/esphome/esphome) from 2026.4.2 to
    2026.4.5.
    <h2>2026.4.5</h2>
    <li>[ha-addon] Add opt-in toggle for the new ESPHome Device Builder <a
    href="https://redirect.github.com/esphome/esphome/pull/16247">esphome#16247</a>
    href="https://github.com/jesserockz"><code>@ jesserockz</code></a></li>
    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
2026-05-22 Bump idna from 3.11 to 3.15 (#210)
    Bumps [idna](https://github.com/kjd/idna) from 3.11 to 3.15.
    <summary>Changelog</summary>
    href="https://github.com/kjd/idna/blob/master/HISTORY.md">idna's
    changelog</a>.</em></p>
    <h2>3.15 (2026-05-12)</h2>
    <li>Enforce DNS-length cap on individual labels early in
    <code>check_label</code>,
    short-circuiting contextual-rule processing for oversized input
    while staying compatible with UTS 46 usage.</li>
    <li>Tidy core helpers: hoist bidi category sets to module-level
    frozensets (avoiding per-codepoint list construction), simplify
    length checks, and reuse the shared <code>_unicode_dots_re</code> from
    <code>idna.co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
2026-06-30 Bump esphome from 2026.5.1 to 2026.6.3 (#218)
    Bumps [esphome](https://github.com/esphome/esphome) from 2026.5.1 to
    2026.6.3.
    <h2>2026.6.3</h2>
    <li>Bump zeroconf from 0.149.16 to 0.150.0 <a
    href="https://redirect.github.com/esphome/esphome/pull/17137">esphome#17137</a>
    href="https://github.com/apps/dependabot"><code>@ dependabot[bot]</code></a></li>
    <li>[espidf] Don't fail framework check on broken unrelated PATH tools
    <a
    href="https://redirect.github.com/esphome/esphome/pull/17053">esphome#17053</a>
    href="https:/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
2026-07-06 Bump esphome from 2026.6.3 to 2026.6.4 (#223)
    Bumps [esphome](https://github.com/esphome/esphome) from 2026.6.3 to
    2026.6.4.
    <h2>2026.6.4</h2>
    <li>[adc] Only call cyw43_thread_enter/exit for VSYS when WiFi is active
    on RP2040 <a
    href="https://redirect.github.com/esphome/esphome/pull/17203">esphome#17203</a>
    by <a href="https://github.com/jlunz"><code>@ jlunz</code></a></li>
    <li>[config_validation] Fix multicast typo in error message <a
    href="https://redirect.github.com/esphome/esphome/pull/17206">esphome#17206</a>
    href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
2026-07-27 Bump esphome from 2026.6.4 to 2026.6.5 (#226)
    Bumps [esphome](https://github.com/esphome/esphome) from 2026.6.4 to
    2026.6.5.
    <h2>2026.6.5</h2>
    <li>Bump bundled esphome-device-builder to 1.0.24 <a
    href="https://redirect.github.com/esphome/esphome/pull/17332">esphome#17332</a>
    href="https://github.com/apps/esphome"><code>@ esphome[bot]</code></a></li>
    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
2026-08-16 fix(desk_command): publish M4 / preset-4 button (bit lives in byte 5) (#208)
    Fixes the issue where pressing the **M4 / preset-4** button on an
    EQ5-style keypad never produces a value on the `desk_command` sensor.
    ## Root cause
    `DeskCommandSensor::loop()` only inspected byte 4 of the Loctek command
    packet and routed `byte4 == 0x00` to `value = 8` (release). The M4
    button transmits its bit in **byte 5** (`9B 06 02 00 01 AC 60 9D`), so
    its presses were indistinguishable from a release — and silently dropped
    whenever the previous published value was already 8 (the typical case
    right after any other button is released).
    ## What this PR changes
    - `history` extended from 3 to 4 entries so byt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
2026-08-16 Bump actions/setup-python from 6 to 7 (#228)
    Bumps [actions/setup-python](https://github.com/actions/setup-python)
    from 6 to 7.
    href="https://github.com/actions/setup-python/releases">actions/setup-python's
    <h2>v7.0.0</h2>
    <h2>What's Changed</h2>
    <h3>Enhancements</h3>
    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
2026-10-11 Bump anyio from 4.12.0 to 4.14.2 (#242)
    Bumps [anyio](https://github.com/agronholm/anyio) from 4.12.0 to 4.14.2.
    href="https://github.com/agronholm/anyio/releases">anyio's
    <h2>4.14.2</h2>
    <li>Changed <code>ByteReceiveStream.receive()</code> implementations to
    raise a <code>ValueError</code> when <code>max_bytes</code> is not a
    positive integer (<a
    href="https://redirect.github.com/agronholm/anyio/pull/1191">#1191</a>)</li>
    <li>Fixed <code>CapacityLimiter.total_tokens</code> rejecting
    <code>float(&quot;inf&quot;)</code> when the limiter was instantiated
    outside of an event loop. The adap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
2026-10-11 Bump virtualenv from 20.36.1 to 21.7.13 (#247)
    Bumps [virtualenv](https://github.com/pypa/virtualenv) from 20.36.1 to
    21.7.13.
    href="https://github.com/pypa/virtualenv/releases">virtualenv's
    <h2>21.7.13</h2>
    <!-- raw HTML omitted -->
    <li>👷 ci: correct a stale checkout pin comment by <a
    href="https://github.com/gaborbernat"><code>@ gaborbernat</code></a> in
    href="https://redirect.github.com/pypa/virtualenv/pull/3254">pypa/virtualenv#3254</a></li>
    <li>🔧 chore: drop misc as a changelog fragment type by <a
    href="https://github.com/gaborbernat"><code>@ ga
    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
2026-10-11 Correct Preset 3 and 4 commands and add substitutions (#115)
    Preset 3 button currently issues the command for Preset 4 and vice
    versa.
    Added substitutions so that Sit / Stand can be configured to different
    presets numbers other than 3 and 4.
    ---------
2026-10-11 Add ESP32-C3 to the pinout table (#127)
    Hi there,
    Thanks for this project! I've successfully used it with ESP32-C3, but
    had to use different pins.
    So I thought it might be helpful to share this with others in the pinout
    table.
    I've also marked RJ45 pin colors in the table for convenience.
    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
2026-10-12 Add Modelfiles for passthrough case (#149)
2026-10-13 Bump ruff from 0.16.10 to 0.17.0 (#249)
    Bumps [ruff](https://github.com/astral-sh/ruff) from 0.16.10 to 0.17.0.
    <h2>0.17.0</h2>
    <p>Released on 2026-10-09.</p>
    <p>The executables in our macOS and Windows release archives and
    <code>ruff</code> wheels are now code-signed. macOS executables are
    signed with an Apple Developer ID certificate and notarized by Apple.
    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
2026-10-17 Change framework type from Arduino to ESP-IDF (#222)
    If we change the framework to esp-idf, this will also work with ESP32-C6
    chips, as ESPHome does not allow arduino on ESP-C6 and everything still
    compiles just fine.
    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
2026-10-17 Bump esphome to 2026.9.1 and require Python 3.12 (#250)
    esphome 2026.9.1 requires Python >=3.12. Because `requires-python` still
    allowed 3.11, uv could not resolve the upgrade, so Dependabot never
    proposed it and its security updates failed. esphome pins its
    dependencies exactly, which kept vulnerable versions locked.
    - `requires-python` raised to `>=3.12`; the lint matrix now runs 3.12,
    3.13 and 3.14 (3.11 dropped; esphome supports `<3.15`)
    - esphome 2026.6.5 → 2026.9.1, plus the resulting lockfile updates:
    pillow 12.2.0 → 12.3.0 and py7zr 1.1.0 → 1.1.3, and tornado is no longer
    a dependency
    - starlette is updated to 0.52.1 but stays below the fixed versions: it
    comes from `platformi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
2026-10-28 Bump esphome from 2026.9.1 to 2026.10.0 (#256)
    Bumps [esphome](https://github.com/esphome/esphome) from 2026.9.1 to
    2026.10.0.
    <h2>2026.10.0</h2>
    <p><a
    href="https://esphome.io/changelog/2026.10.0.html">https://esphome.io/changelog/2026.10.0.html</a></p>
    <h2>2026.10.0b6</h2>
    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
2026-10-28 Document accessory-port behaviour of the CB38M2J(IB)-1 (heartbeat, height reporting, CRC16-Modbus) (#233)
    Documents the behaviour of the control box CB38M2J(IB)-1 (Flexispot E7 /
    E1L, listed under HS13B-1) on its spare HS RJ45 jack, as notes under
    *Retrieve current height*. Findings from an ESP32 in the spare jack with
    the original control panel in the other, verified on a live Flexispot
    E1L, last tested 2026-10-18.
    **Findings**
    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
2026-10-28 Fix key release on 5-byte keypad frames and map M4 in pass-through (#260)
    Since #208, the desk command sensor reads byte 5 as a second key byte
    for both 6-byte and 5-byte frames. On 5-byte keypads such as the HS01B-1
    (#146) byte 5 is the checksum, so a release frame `9B 05 02 00 A1 60 9D`
    decodes as ~16.33 instead of 8. In pass-through, Up/Down are then never
    released and keep moving until the min/max height.
    - Only decode byte 5 as a key byte for 6-byte frames.
    - Map value 9 (M4, added in #208) to the Sit preset in
    `office-desk-esp32-passthrough.yaml`.
    Replaying frames through the decoder loop:
    | Frames | Before | After |
    |---|---|---|
    | 5-byte up, release, down, release | 1, 16.33, 2, 1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
